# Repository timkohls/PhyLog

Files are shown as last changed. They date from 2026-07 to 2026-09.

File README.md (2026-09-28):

<div align="center">
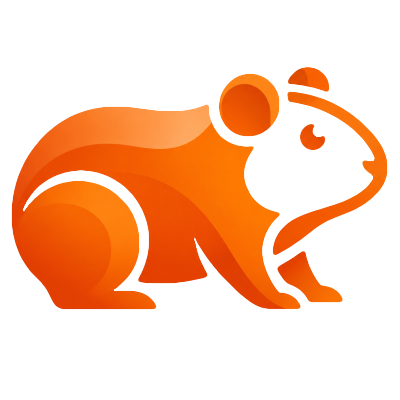
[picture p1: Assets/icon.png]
PhyLog Logo
  

# PhyLog

Digitale Messwerterfassung für den Physikunterricht, ein ESP32, die wichtigsten Sensoren, unter 50 € pro Messplatz.

</div>

---

## Worum geht's

> „Ziel ist nicht das bessere Messgerät zu entwickeln, sondern mehr selbstständiges Experimentieren zu ermöglichen."

Ein Klassensatz Vernier - oder Leybold-Equipment kostet schnell so viel wie ein Kleinwagen – entsprechend selten stehen genug Geräte für echtes Experimentieren zur Verfügungund aus vielen Versuchen werden Frontalvorführungen. PhyLog will das ändern, ein ESP32 und austauschbare Sensormodule ergeben einen Messplatz für einen Bruchteil der üblichen Kosten. Steckbar, offen dokumentiert und mit einer Desktop-Software, die live mitschreibt.

**Woraus das Ganze besteht:**

<div align="center">
  PhyLog Architektur: Software, ESP32, Sensormodule
</div>

---

Die Hardware besteht aus dem ESP32-Hub und den verschiedenen steckbaren Sensormodulen. Alle benötigten 3D-Druckdateien, Pinouts und weiteren Hardware-Dateien befinden sich im Hardware-Ordner.

Wenn du einen eigenen PhyLog-Messplatz aufbauen möchtest, findest du dort auch eine ausführliche Hardware Quickstart-Anleitung. Diese beschreibt den Aufbau und die Verkabelung der Sensoren und des ESP32-Hubs sowie die Installation der benötigten Treiber, das Aufspielen der Firmware und die erste Verbindung mit PhyLog.

---

## Quickstart

1. **PhyLog anschließen.** Per USB-Kabel oder – wenn das Board vorher schon einmal gekoppelt wurde – per Bluetooth. Oben rechts im Hauptfenster Com-Port auswählen und "Verbinden" klicken oder die Lupe dann sucht PhyLog den richtigen Port automatisch über einen kurzen Handshake.
2. **Sensoren zuweisen.** Über *Sensor → Sensor konfigurieren…* für Kanal A und/oder B den passenden Sensortyp wählen und bei Bedarf kalibrieren (siehe unten). Live-Werte zeigt der Dialog dabei direkt an, man sieht also sofort, ob der Sensor etwas liefert.
3. Mit **Start** loslegen. Ohne Schwellenwert-Trigger beginnt die Aufzeichnung sofort; mit Trigger wartet PhyLog, bis die konfigurierte Flanke auftritt, und nimmt dank Vorlaufpuffer auch die Millisekunden *vor* dem eigentlichen Auslöser mit auf.
4. **Auswerten.** Im Diagramm zoomen (Rubberband oder Freihand), einen Fit durchlegen, Chi² ablesen – und am Ende als CSV oder PNG rausschreiben.

Wer nur schnell einen einzelnen Messwert braucht (z. B. für eine Wertetabelle mit mehreren Positionen statt einer Zeitreihe), nutzt statt "Start" den **Momentaufnahme**-Knopf: der trägt den aktuellen Live-Wert als neue Zeile mit fortlaufendem Index statt Zeitstempel ein.

---

## Was die Software kann

**Live-Erfassung & Trigger**
Zwei unabhängige Kanäle (A/B), durchgehendes Streaming vom Gerät, sodass Live-Anzeigen und Kalibrierung auch ohne laufende Aufzeichnung aktuelle Werte zeigen. Start entweder manuell per Knopfdruck oder über einen Schwellenwert-Trigger (steigende/fallende Flanke, einstellbare Vorlaufzeit, optionales Zeitlimit).

**Diagramm**
Zoomen per Rubberband oder Freihand-Auswahl, Zoom-Buttons, gemeinsame oder getrennte Y-Achse für Kanal A/B, gerade/glatte (Spline) Linienverbindung. Regressionen für linear, Polynom (Grad wählbar), Sinus und Exponentialfunktion, dazu reduziertes Chi² zur Bewertung der Fit-Güte – inklusive automatischer Sigma-Schätzung aus den Residuen, falls keine Messunsicherheit von Hand eingetragen wurde.

**Sensoren (steckbar)**
INA219 für Strom, VEML7700 für Beleuchtungsstärke, HX711 für Kraft/Gewicht, INMP441-Mikrofon (als Schalldruckpegel oder live als Frequenzspektrum), ein KY-003-Hall-Sensor für Drehzahl-/Periodendauermessungen sowie ein generischer 0–16V-Spannungsteiler und ein DS18B20-Digitalthermometer. Jeder Sensor mit Kalibrierbedarf bringt seinen eigenen Dialog mit.

**Import/Export**
CSV-Import gezielt pro Kanal (die Software fragt beim Öffnen, ob die Datei nach A oder B soll – so lassen sich zwei frühere Messungen nacheinander laden, ohne dass sich die Kanäle gegenseitig überschreiben), CSV-Export getrennt je Kanal, Diagramm-Export als PNG.

**Verbindung**
USB und Bluetooth SPP, automatische Geräteerkennung per Handshake statt Rate-Raten über die COM-Port-Liste, ein eingebautes Terminal für rohe Kommandos an die Firmware.

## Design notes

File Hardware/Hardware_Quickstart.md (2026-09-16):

# PhyLog Hardware – Quickstart

Dieser Quickstart beschreibt den Aufbau der PhyLog-Hardware sowie das erste Bespielen und Verbinden des ESP32.

PhyLog besteht aus einem ESP32-Hub und verschiedenen steckbaren Sensormodulen. Die Sensormodule können je nach benötigter Messgröße ausgetauscht und erweitert werden. Die verfügbaren Sensoren und die zugehörigen Hardware-Dateien befinden sich im Ordner [`Hardware/prints`](https://github.com/timkohls/PhyLog/tree/main/Hardware/prints).

## 1. 3D-Druck

Alle benötigten Gehäuseteile müssen zunächst ausgedruckt werden.

Für den ESP32 wird einmal der

- `ESP_Bottom`

- `ESP_Top`

benötigt.

Für die Sensoren gibt es ein gemeinsames `Sensor_Top`, das für alle Sensoren verwendet werden kann. Für jeden Sensortyp wird zusätzlich das jeweils passende `*_Sensor_Bottom` benötigt.

Die Anzahl der zu druckenden Sensor-Bottoms richtet sich daher danach, wie viele Sensoren des jeweiligen Typs gebaut werden sollen.

Aktuell liegen unter anderem Bottoms für Strom, Spannung, Kraft, Licht, Magnetfeld, Schall und Temperatur sowie ein gemeinsames Sensor-Top und ESP-Gehäuse im Repository.

## 2. Sensoren aufbauen

Die jeweilige Sensorplatine wird in das passende Bottom eingesetzt und mit **M3 × 4 mm Schrauben** befestigt.

Die Verdrahtung zwischen Sensor und ESP32 ist dem [Pinout](https://github.com/timkohls/PhyLog/blob/main/Hardware/pinout.md) zu entnehmen. Dort ist für die verschiedenen Sensortypen angegeben, welche RJ45-Pins mit welchen ESP32-Pins verbunden werden müssen.

Dabei gilt grundsätzlich:

- **Pin 1:** GND

- **Pin 8:** VCC

- Die übrigen verwendeten Pins hängen vom Sensortyp und vom verwendeten Kommunikationsprotokoll ab.

Nach dem Einsetzen und Verkabeln wird das gemeinsame Sensor-Top aufgesetzt und ebenfalls mit **M3 × 4 mm Schrauben** befestigt.

Damit ist das Sensormodul fertig.

Der ESP32-Hub wird auf die gleiche Weise aufgebaut: ESP32 in das `ESP_Bottom` einsetzen, befestigen und anschließend das `ESP_Top` mit M3 × 4 mm Schrauben verschließen.

## 4. Firmware auf den ESP32 spielen

Bevor ein ESP32 zum ersten Mal bespielt werden kann, muss auf dem verwendeten Rechner der passende **CH340/CH341-Treiber** installiert werden.

Der benötigte Treiber befindet sich bereits im Repository unter:

```
Firmware/CH341SER/
```

Der dort enthaltene Treiber wurde von der **Nanjing Qinheng Microelectronics (WCH)**-Website heruntergeladen und unverändert in das Repository übernommen. Er ist **kein Bestandteil der PhyLog-Software**, sondern eine benötigte Drittanbieter-Komponente, die für die USB-Kommunikation mit dem ESP32 bereitgestellt wird.

Die Originalquelle des Treibers ist:

**WCH – CH341SER USB-to-Serial Driver**  
https://www.wch-ic.com/downloads/CH341SER_ZIP.html

Die Firmware befindet sich unter:

```text
Firmware/PhyLog_firmware/PhyLog_firmware.ino
```

Die `.ino`-Datei kann direkt mit der **Arduino IDE** geöffnet werden.

Arduino erkennt die benötigten Bibliotheken normalerweise automatisch. Falls die ESP32-Unterstützung noch nicht installiert ist, muss das **ESP32 Dev Module** bzw. die ESP32-Board-Unterstützung über den Board Manager installiert werden.

Die Installation kann etwas dauern, da Arduino dabei zusätzliche Komponenten herunterlädt. Die offizielle ESP32-Unterstützung wird über das Arduino-ESP32-Paket bereitgestellt.

Anschließend:

1. ESP32 per USB mit dem Rechner verbinden.

2. In Arduino das entsprechende **ESP32 Dev Module** auswählen.

3. Den vom ESP32 verwendeten **COM-Port** auswählen.

4. Die Firmware mit **Upload** auf den ESP32 übertragen.

5. Warten, bis Arduino **`Upload Done`** meldet.

Falls der ESP32 nicht als COM-Port auftaucht, zunächst überprüfen, ob der CH340/CH341-Treiber korrekt installiert wurde.

## 5. Erste Verbindung mit PhyLog

Nach erfolgreichem Flashen kann der ESP32 zum ersten Mal mit der PhyLog-Software verbunden werden.

Am einfachsten ist die erste Verbindung zunächst über **USB**.

ESP32 anschließen und in PhyLog oben rechts die Verbindung herstellen. Der bevorzugte Weg ist die **automatische Portsuche**. PhyLog sucht dabei nach dem passenden Gerät und überprüft die Verbindung über einen Handshake.

Alternativ kann der COM-Port auch manuell über das Dropdown-Menü ausgewählt werden.

### Verbindung testen

Um zu überprüfen, ob die Firmware korrekt funktioniert, kann das integrierte **Terminal** geöffnet werden.

Den ESP32 einmal anpingen.

Wenn alles korrekt funktioniert, sollte eine **Hello-Antwort mit der entsprechenden Firmware-/Payload-Version** zurückkommen.

Ist dies der Fall, funktionieren:

- ESP32

- USB-Verbindung

- Treiber

- Firmware

- Kommunikation mit PhyLog

korrekt.

## 6. Fehlerbehebung bei USB

Wenn kein COM-Port angezeigt wird oder keine Verbindung hergestellt werden kann, sollten die folgenden Punkte überprüft werden:

1. Ist der CH340/CH341-Treiber installiert?

2. Wird der ESP32 im Geräte-Manager als COM-Port erkannt?

3. Ist in Arduino das richtige ESP32-Board ausgewählt?

4. Wurde die Firmware erfolgreich mit **`Upload Done`** übertragen?

5. Ist der richtige COM-Port ausgewählt?

6. Funktioniert die Kommunikation über das PhyLog-Terminal?

Wenn der ESP32 bereits erfolgreich geflasht wurde, aber keine Verbindung zustande kommt, sollte zunächst der USB-Anschluss und anschließend die automatische bzw. manuelle COM-Port-Auswahl überprüft werden.

## 7. Verbindung über Bluetooth

PhyLog unterstützt neben USB auch **Bluetooth SPP**.

Wenn Bluetooth verwendet werden soll, muss der ESP32 auf jedem Rechner, mit dem er verwendet werden soll, zunächst einmal ganz normal über die Bluetooth-Einstellungen des Betriebssystems gekoppelt werden.

Dazu:

1. ESP32 mit Strom versorgen.

2. Bluetooth-Einstellungen des Rechners öffnen.

3. Den ESP32 auswählen und koppeln.

4. PhyLog starten.

5. Oben rechts die automatische Portsuche verwenden oder den entsprechenden Port manuell auswählen.

> **Hinweis:** Die Bluetooth-Suche dauert etwas länger als die USB-Suche. Währenddessen zeigt PhyLog oben im Statusbereich an, was gerade passiert.

Nach erfolgreicher Verbindung kann der ESP32 genauso wie über USB verwendet werden.

## 8. Kurzfassung

```text
3D-Druck
   ↓
ESP-Bottom + ESP-Top
Sensor-Bottom + gemeinsames Sensor-Top
   ↓
Sensorplatinen mit M3 × 4 mm befestigen
   ↓
Nach pinout.md verkabeln
   ↓
Gehäuse schließen
   ↓
CH340/CH341-Treiber installieren
   ↓
PhyLog_firmware.ino in Arduino öffnen
   ↓
ESP32 Dev Module auswählen
   ↓
COM-Port auswählen
   ↓
Firmware hochladen
   ↓
"Upload Done"
   ↓
ESP32 mit PhyLog verbinden
   ↓
Terminal öffnen und ESP32 anpingen
   ↓
Hello + Payload-Version erhalten
   ↓
Fertig
```

Weitere Informationen zu Pinbelegung, Hardware und verfügbaren Komponenten befinden sich direkt im `Hardware`-Ordner des Projekts.

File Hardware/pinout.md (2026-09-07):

# Pinout

| **RJ45-Pin** | **Sensor A (ESP-Pin)** | **Sensor B (ESP-Pin)** | **I2C-Sensor** | **I2S-Sensor** | **2WS-Sensor** | **Analog-Sensor** |
| --- | --- | --- | --- | --- | --- | --- |
| **1** | Ground | Ground | Ground | Ground | Ground | Ground |
| **2** | D32 | D27 | SDA | WS | DOUT | Analog |
| **3** | D33 | D26 | SCL | SCK | SCK | *leer* |
| **4** | D35 | D25 | *leer* | SD | *leer* | *leer* |
| **5** | *leer* | *leer* | *leer* | *leer* | *leer* | *leer* |
| **6** | *leer* | *leer* | *leer* | *leer* | *leer* | *leer* |
| **7** | *leer* | *leer* | *leer* | *leer* | *leer* | *leer* |
| **8** | VCC | VCC | VCC | VCC | VCC | VCC |
| **9** | *leer* | *leer* | *leer* | *leer* | *leer* | *leer* |

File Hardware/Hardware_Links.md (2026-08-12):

# Preisliste Hardware

| Menge | Hardware | Links | Preis (nach Menge) |
| ----- | --- | --- | --- |
| 1/2 x | ESP 32 | https://www.amazon.de/dp/B0DHRV7784 | 5,49 € |
| 1/2 x | Strom | https://www.amazon.de/dp/B0FWJV9V54 | 2,99 € |
| 1/5 x | Spannung | https://www.amazon.de/-/en/dp/B07DJ5TGL8 | 0,99 € |
| 1/2 x | Wägezelle | https://www.amazon.de/dp/B0G6YGMVN9 | 5,09 € |
| 1/2 x | Lichtsensor | https://www.amazon.de/dp/B0C3VC5H6M | 4,49 € |
| 1/3 x | Schallsensor | https://www.amazon.de/dp/B0GXZC7T7H | 2,49 € |
| 1/5 x | Temperatursensor (+Spannungsteiler s. o.) | https://www.amazon.de/dp/B0GLXCGXCW | 2,98 € |
| 1/5 x | Hallsonde | https://www.amazon.de/dp/B07DJ5HXHM | 0,99 € |
| 1 x | RJ45 (Pack of 7) | https://www.amazon.de/dp/B0F4MWBK5H | 8,99 € |
| 2 x | RJ45 Cable | https://www.amazon.de/dp/B00N2VILDM | 3,98 € |
| 1 x | Jumper Cable (40) | https://www.amazon.de/dp/B07KYHBVR7 | 2,49 € |
| 1/5 x | PLA (200g) | https://www.amazon.de/dp/B0BTHSVQ89/ | 2,99 € |
| 1/4 x | Schrauben | https://www.amazon.de/dp/B0GYTDFYBG | 2,09 € |
| | | | **46,05 €** |

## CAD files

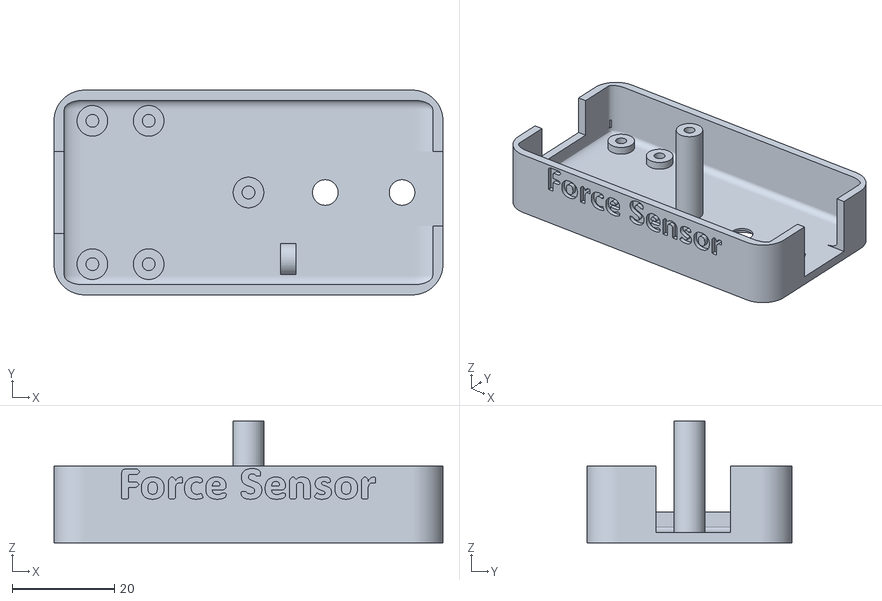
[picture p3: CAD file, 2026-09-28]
Hardware/prints/Force_Sensor_Bottom_V1.3.stl
76.0 x 40.0 x 23.8

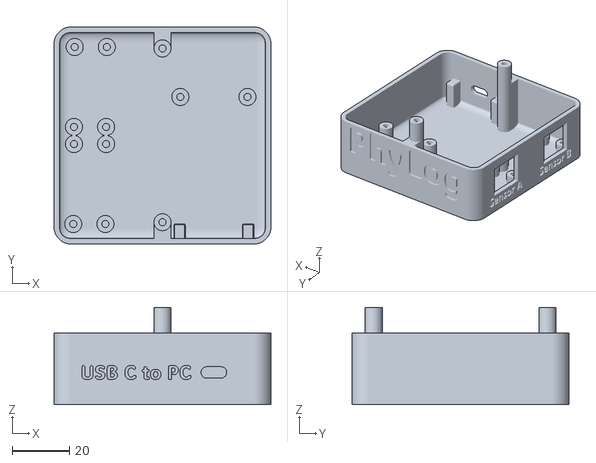
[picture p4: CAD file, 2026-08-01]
Hardware/prints/ESP_Bottom_V1.6.stl
76.0 x 76.0 x 34.0

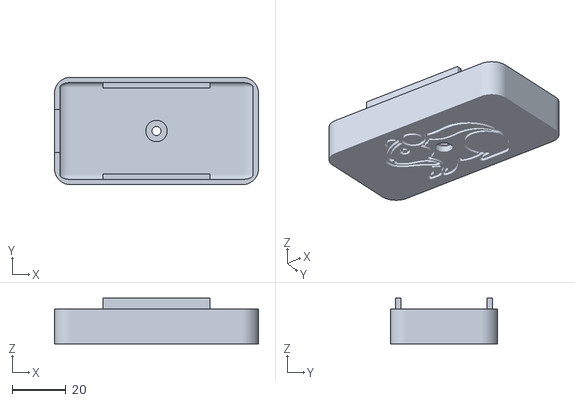
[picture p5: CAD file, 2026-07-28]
Hardware/prints/Sensor_Top_V1.5.stl
76.0 x 40.0 x 17.0

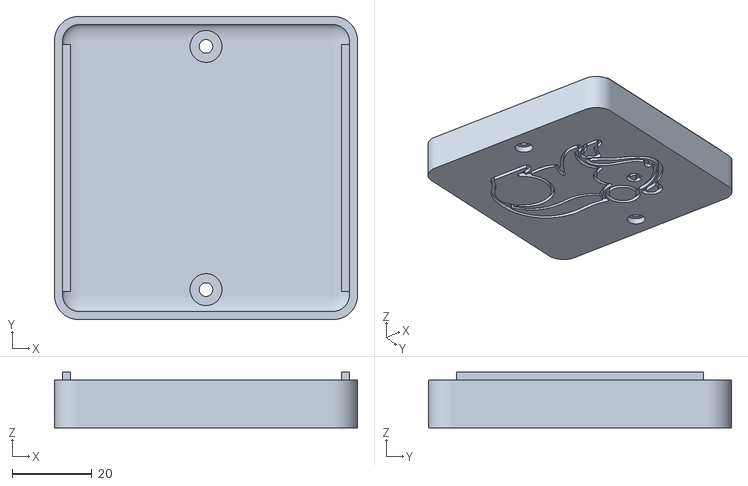
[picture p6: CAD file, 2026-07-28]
Hardware/prints/ESP_Top_V1.3.stl
76.0 x 76.0 x 14.0

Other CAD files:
Hardware/prints/Voltage_Sensor_Bottom_V1.1.stl
Hardware/prints/Temperature_Sensor_Bottom_V1.0.stl
Hardware/prints/Magnet_Sensor_Bottom_V1.1.stl
Hardware/prints/Light_Sensor_Bottom_V1.5.stl
Hardware/prints/Sound_Sensor_Bottom_V1.4.stl
Hardware/prints/Current_Sensor_Bottom_V1.4.stl

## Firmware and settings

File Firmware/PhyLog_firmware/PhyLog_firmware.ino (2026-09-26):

/*
 * PhyLog Firmware v9.2
 *
 * Steuert zwei unabhängige Messkanäle (A/B) über USB und Bluetooth. Ein Kanal bekommt seinen
 * Sensortyp per SET,<Kanal>,<Typ>[,<Konfiguration>] vom Host zugewiesen und startet immer bei
 * TYPE_NONE. Die Firmware kennt dabei keine konkreten Sensormodelle, nur generische Bus-Muster:
 *
 *   ANALOG    Pin2=Eingang                           keine Konfiguration
 *   DIGITAL   Pin2=Eingang                           keine Konfiguration
 *   I2C       Pin2=SDA, Pin3=SCL                     Adresse + Init-/Lese-Register, siehe parseI2CSetPayload
 *   I2S       Pin2=WS, Pin3=BCLK, Pin4=SD            Modus, Abtastrate, Slot, Bit-Shift, Null-Check, siehe parseI2SSetPayload
 *   ONEWIRE   Pin2=Datenleitung (ext. Pull-up 4,7kΩ) opt. Init-Writes + Konversions-/Lesekommando + Byte-Layout, siehe parseOneWireSetPayload
 *   HX711     Pin2=DOUT, Pin3=SCK                    keine Konfiguration (eigenes Protokoll)
 *
 * Ein neuer Sensor mit einer dieser Schnittstellen braucht deshalb kein Firmware-Update, nur eine
 * neue Java-Klasse (siehe I2CSensor.java/OneWireSensor.java/I2SSensor.java). Vorausgesetzt wird
 * dabei das jeweilige generische Muster - ein grundlegend anderes Protokoll bräuchte weiterhin ein Firmware-Update.
 *
 * Kanal A und B hängen an physisch getrennten Bussen (I2C: Wire/Wire1, I2S: Port 0/1), damit
 * beide gleichzeitig denselben Typ nutzen können.
 *
 * Host-Protokoll (zeilenbasiert, '\n'-terminiert, identisch über USB und Bluetooth):
 *   Host -> ESP32:  PING | START | STOP | RATE,<Hz> | SET,<Kanal>,<Typ>[,<Konfiguration>]
 *   ESP32 -> Host:  #HELLO,...              Antwort auf PING sowie einmalig beim Start
 *                   #OK,<Kommando>[,...]    Bestätigung
 *                   #ERR,<Tag>,<Kanal>      Sensor-/Konfigurationsfehler (gedrosselt, siehe reportSensorError)
 *                   D,<ms>,<Kanal>,<Slot>,<Rohwert>          ein Messwert (siehe sendDataPacket)
 *                   #SPEC,<Kanal>,<Bins>,<Rate>,<dB*10>,...   ein Frequenzspektrum (siehe sendSpectrumPacket)
 *
 * Aufbau dieser Datei:
 *   1. Konstanten    2. Typen/Structs    3. Laufzeitzustand    4. Host-Kommunikation
 *   5. Low-Level-GPIO    6. Sensortreiber (I2C, HX711, 1-Wire, I2S inkl. FFT)
 *   7. Kanal-Hardware (Freigabe/Konfiguration)    8. Parser für SET-Payloads
 *   9. Kommando-Verarbeitung    10. Abtast-Dispatcher    11. setup()/loop()
 *
 * Hardware-Notizen:
 * - Kanal-A-Pins: GPIO32/33/35 (ADC1-fähig, keine Strapping-Pins). Kanal B: GPIO27/26/25.
 *   Nicht ändern, ohne ADC-Tauglichkeit/Strapping-Pin-Eigenschaften der Ziel-GPIOs zu prüfen.
 * - HX711 und 1-Wire nutzen direkten GPIO-Registerzugriff statt digitalWrite()/digitalRead(),
 *   da deren IO-MUX-Overhead das µs-genaue Timing beider Protokolle sprengen würde.
 */

#include <Wire.h>
#include <driver/i2s_std.h>
#include <math.h>
#include "soc/gpio_struct.h"
#include "BluetoothSerial.h"

#if !defined(CONFIG_BT_ENABLED) || !defined(CONFIG_BLUEDROID_ENABLED)
#error Bluetooth ist im Board-/Menuconfig-Profil deaktiviert - Partition Scheme mit \
       Bluetooth-Unterstützung wählen (siehe Dateikopf).
#endif


// =====================================================================================
// 1. KONSTANTEN
// =====================================================================================

// --- Allgemein / Host-Verbindung ---

/** Begrüßungszeile, Antwort auf PING und einmalige Meldung beim Start. */
const char *HELLO_MESSAGE = "#HELLO,PhyLog-ESP32,fw=9.2\n";

/** Serielle Baudrate zum PC - muss mit GUI.java (DeviceConnection.connect) und Terminal.java
 *  übereinstimmen, sonst verbindet sich nichts mehr. */
const long BAUD_RATE = 460800;

/** Name in der Bluetooth-Geräteliste des PCs. */
const char *BT_DEVICE_NAME = "PhyLog Bluetooth";

/** Mindestabstand zwischen zwei an den Host gemeldeten Fehlern desselben Kanals, damit ein
 *  dauerhaft fehlschlagender Sensor den Host nicht mit #ERR-Zeilen flutet. */
const unsigned long ERROR_REPORT_MIN_INTERVAL_MS = 120;

// --- Pinbelegung ---

/** Die drei Signal-Pins eines Kanal-Ports, Rolle je nach Sensortyp (siehe
 *  configureChannelHardware): I2C=SDA/SCL, HX711=DOUT/SCK, I2S=WS/BCLK/SD, Analog/Digital/
 *  1-Wire nutzen nur [0]. GPIO 0/2/5/12/15 sind ESP32-Strapping-Pins und bewusst nicht belegt. */
const int PINS_CHANNEL_A[3] = {32, 33, 35};
const int PINS_CHANNEL_B[3] = {27, 26, 25};

// --- I2C ---

/** Anzahl aufeinanderfolgender I2C-Fehler je Kanal, ab der der Bus automatisch neu
 *  initialisiert wird (siehe noteI2CResult). */
const int I2C_FAIL_STREAK_RESET_THRESHOLD = 20;

// --- HX711 ---

/** Maximale Zeit in ms, die DOUT durchgehend HIGH bleiben darf, bevor ein HX711-Fehler gemeldet
 *  wird (siehe sampleHX711). */
const unsigned long HX711_TIMEOUT_MS = 1000;

// --- I2S-Mikrofon ---

/** Wie viele I2S-Rohsamples je Zyklus für den Spitzenwert gelesen werden, richtet sich dynamisch
 *  nach der konfigurierten Abtastrate (siehe i2sReadSampleCount), begrenzt auf diesen Bereich. */
const int MIC_MIN_READ_SAMPLES = 16;
const int MIC_MAX_READ_SAMPLES = 512;

/** Anzahl aufeinanderfolgender komplett nullwertiger I2S-Fenster, ab der erst von einer echten
 *  Diskonnektion statt einer legitimen kurzen Stille ausgegangen wird (siehe sampleI2SRaw/
 *  captureAndSendSpectrum). */
const int I2S_ZERO_STREAK_THRESHOLD = 5;

// --- Frequenzspektrum (I2S im Modus SPEC) ---

/** FFT-Größe für den Live-Frequenzspektrum-Modus - Zweierpotenz (Voraussetzung der iterativen
 *  Radix-2-FFT in computeFFT). Ein reelles Signal liefert nur n/2 unabhängige Frequenz-Bins. */
const int SPECTRUM_FFT_SIZE = 1024;
const int SPECTRUM_OUTPUT_BINS = SPECTRUM_FFT_SIZE / 2;

/** Puffergröße für ein komplettes Spektrum-Paket (Header + je Bin bis zu 6 Byte, siehe
 *  sendSpectrumPacket), großzügig genug ohne Neuberechnung pro Bild. */
const size_t SPECTRUM_PACKET_BUF_SIZE = 32 + (size_t) SPECTRUM_OUTPUT_BINS * 7;

/** Mindestabstand zwischen zwei gesendeten Spektren (~16 Bilder/Sekunde bei BAUD_RATE=460800). */
const unsigned long SPECTRUM_INTERVAL_MS = 60;


// =====================================================================================
// 2. TYPEN UND STRUCTS
// =====================================================================================
// Alle Typen stehen bewusst vor jeder Funktion/jedem Prototyp: Die Arduino-IDE fügt
// automatisch generierte Prototypen vor den ersten Funktionen ein, und die müssen die hier
// definierten Typen bereits kennen.

/** Sensortyp eines Kanals. Die Zahlenwerte werden nicht übertragen (das Protokoll nutzt
 *  Klartext-Typnamen), die Lücken bei 3 und 6 haben daher keine Funktion. */
enum SensorType {
  TYPE_NONE = 0,
  TYPE_ANALOG = 1,
  TYPE_I2C = 2,
  TYPE_HX711 = 4,
  TYPE_I2S = 5,
  TYPE_DIGITAL = 7,
  TYPE_ONEWIRE = 8
};

// --- I2C ---

/** Ein Registerschreibvorgang der I2C-Init-Sequenz. */
struct I2CWriteSpec {
  uint8_t reg = 0;
  uint8_t data[4] = {0, 0, 0, 0};
  uint8_t dataLen = 0;
};

/** Ein Register-Lesevorgang je Abtastzyklus eines I2C-Sensors. */
struct I2CReadSpec {
  uint8_t reg = 0;
  uint8_t len = 0;      // 1-4 Byte
  bool bigEndian = true;
  uint8_t slot = 0;
};

const uint8_t MAX_I2C_WRITES = 4;
const uint8_t MAX_I2C_READS = 4;

/** Vom Host per SET-Kommando übertragene I2C-Sensorkonfiguration eines Kanals. */
struct I2CSensorConfig {
  uint8_t address = 0;
  I2CWriteSpec initWrites[MAX_I2C_WRITES];
  uint8_t initWriteCount = 0;
  I2CReadSpec reads[MAX_I2C_READS];
  uint8_t readCount = 0;
};

// --- I2S ---

/** Vom Host per SET-Kommando übertragene I2S-Sensorkonfiguration eines Kanals. */
struct I2SSensorConfig {
  bool spectrumMode = false;
  uint32_t sampleRateHz = 16000;
  bool selectRightSlot = false;  // Slot-Auswahl je nach SEL-Pin-Verdrahtung des Moduls
  uint8_t shiftBits = 8;         // Shift zur Extraktion der gültigen Bits, siehe parseI2SSetPayload
  bool zeroIsError = true;       // durchgängiger Nullwert = Verkabelungsfehler
};

// --- 1-Wire ---

/** Ein einzelner Kommando-Schreibvorgang der 1-Wire-Init-Sequenz (z.B. "Write Scratchpad" beim
 *  DS18B20 zur Auflösungseinstellung). Jeder Eintrag bekommt vor dem Senden von {@code command}
 *  und {@code data} eine eigene Reset+Skip-ROM-Sequenz vorangestellt, siehe configureOneWireSensor. */
struct OneWireWriteSpec {
  uint8_t command = 0;
  uint8_t data[4] = {0, 0, 0, 0};
  uint8_t dataLen = 0;
};

const uint8_t MAX_ONEWIRE_WRITES = 2;

/** Generische 1-Wire-Sensorbeschreibung. "Skip ROM" (0xCC) nimmt die Firmware selbst an -
 *  unterstützt wird nur ein Sensor pro Bus. */
struct OneWireSensorConfig {
  OneWireWriteSpec initWrites[MAX_ONEWIRE_WRITES];
  uint8_t initWriteCount = 0;
  uint8_t convertCmd = 0;
  unsigned long conversionDelayMs = 0;
  uint8_t readCmd = 0;
  uint8_t readLen = 0;
  uint8_t valueOffset = 0;
  uint8_t valueLen = 0;
  bool littleEndian = true;
  bool checkCrc = true;
  uint8_t slot = 0;
};

// --- Prototypen für Funktionen mit Struct-Parametern/-Rückgabewerten ---
// Arduino generiert für alle unten definierten Funktionen automatisch Prototypen, noch bevor
// die obigen Structs bekannt sind - das schlägt für Funktionen mit Struct-Typen in der
// Signatur fehl. Fix: eigene Prototypen hier, direkt nach den Structs (die Arduino-IDE
// erzeugt für bereits deklarierte Funktionen keinen zweiten).
I2CSensorConfig &i2cConfigForChannel(char channelName);
I2SSensorConfig &i2sConfigForChannel(char channelName);
OneWireSensorConfig &oneWireConfigForChannel(char channelName);
bool readOneWireResult(int pin, const OneWireSensorConfig &cfg, long &outValue);
bool parseI2CWriteEntry(const String &entry, I2CWriteSpec &out);
bool parseI2CReadEntry(const String &entry, I2CReadSpec &out);
bool parseI2CWriteList(const String &list, I2CWriteSpec specs[], uint8_t &countOut, uint8_t maxCount);
bool parseI2CReadList(const String &list, I2CReadSpec specs[], uint8_t &countOut, uint8_t maxCount);
bool parseI2SSetPayload(char channelName, const String &params);
bool parseOneWireWriteEntry(const String &entry, OneWireWriteSpec &out);
bool parseOneWireWriteList(const String &list, OneWireWriteSpec specs[], uint8_t &countOut, uint8_t maxCount);


// =====================================================================================
// 3. LAUFZEITZUSTAND
// =====================================================================================

BluetoothSerial SerialBT;

// --- Streaming und Abtasttakt ---

bool isStreaming = false;
unsigned long sampleIntervalMs = 50; // Standard: 20 Hz
unsigned long lastSampleTimeMs = 0;

// --- Sensortyp und Konfiguration je Kanal ---

SensorType configChannelA = TYPE_NONE;
SensorType configChannelB = TYPE_NONE;

I2CSensorConfig i2cConfigChannelA;
I2CSensorConfig i2cConfigChannelB;

I2SSensorConfig i2sConfigChannelA;
I2SSensorConfig i2sConfigChannelB;

OneWireSensorConfig oneWireConfigChannelA;
OneWireSensorConfig oneWireConfigChannelB;

// --- Fehlerdrosselung (siehe reportSensorError) ---

/** Letzter Zeitpunkt einer gemeldeten Fehlermeldung je Kanal. */
unsigned long lastErrorReportMsA = 0;
unsigned long lastErrorReportMsB = 0;

// --- I2C (siehe noteI2CResult) ---

/** Aufeinanderfolgende I2C-Fehler je Kanal. */
int i2cFailStreakA = 0;
int i2cFailStreakB = 0;

// --- HX711 (siehe sampleHX711) ---

/** Ob DOUT aktuell durchgehend HIGH ist (noch kein neuer Wert bereit) und seit wann - Basis für
 *  den Timeout in sampleHX711. Bei Kanalwechsel über releaseChannelHardware zurückgesetzt. */
bool hx711WaitingA = false;
bool hx711WaitingB = false;
unsigned long hx711WaitStartMsA = 0;
unsigned long hx711WaitStartMsB = 0;

// --- 1-Wire (siehe sampleOneWire) ---

/** Ob für den Kanal aktuell eine Konversion läuft, deren Ergebnis noch nicht abgeholt wurde,
 *  und wann sie gestartet wurde. Bei Kanalwechsel über releaseChannelHardware zurückgesetzt. */
bool oneWireConversionPendingA = false;
bool oneWireConversionPendingB = false;
unsigned long oneWireConversionStartMsA = 0;
unsigned long oneWireConversionStartMsB = 0;

// --- I2S (siehe configureI2S, sampleI2SRaw, captureAndSendSpectrum) ---

i2s_chan_handle_t micHandleA = NULL;
i2s_chan_handle_t micHandleB = NULL;

/** Aufeinanderfolgende komplett nullwertige I2S-Fenster je Kanal, siehe I2S_ZERO_STREAK_THRESHOLD. */
int i2sZeroStreakA = 0;
int i2sZeroStreakB = 0;

/** Zeitpunkt des zuletzt gesendeten Spektrums je Kanal. */
unsigned long lastSpectrumTimeMsA = 0;
unsigned long lastSpectrumTimeMsB = 0;

/** Vorberechnetes Hann-Fenster für captureAndSendSpectrum - identisch für jeden Frame, spart
 *  Neuberechnung je Frame. */
float hannWindow[SPECTRUM_FFT_SIZE];
bool hannWindowReady = false;


// =====================================================================================
// 4. HOST-KOMMUNIKATION UND KANAL-ZUORDNUNG
// =====================================================================================

/** hostWrite()/hostPrint() schreiben immer auf USB und zusätzlich auf Bluetooth, sofern dort
 *  ein Client verbunden ist. */
void hostWrite(const char *data, size_t len) {
  Serial.write((const uint8_t *) data, len);
  if (SerialBT.hasClient()) {
    SerialBT.write((const uint8_t *) data, len);
  }
}

void hostPrint(const char *s) {
  hostWrite(s, strlen(s));
}

/** Verschickt einen Messwert als Zeile {@code D,<millis>,<Kanal>,<Slot>,<Rohwert>}. Der Slot
 *  unterscheidet mehrere Werte eines Sensors (z.B. Strom/Spannung beim INA219). */
void sendDataPacket(char channel, int slot, long rawValue) {
  char buf[48];
  int len = snprintf(buf, sizeof(buf), "D,%lu,%c,%d,%ld\n", millis(), channel, slot, rawValue);
  hostWrite(buf, len);
}

/** Meldet einen fehlgeschlagenen Sensorzugriff als {@code #ERR,<Tag>,<Kanal>} (gedrosselt auf
 *  ERROR_REPORT_MIN_INTERVAL_MS je Kanal). */
void reportSensorError(char channelName, const char *errorTag) {
  unsigned long &lastReport = (channelName == 'A') ? lastErrorReportMsA : lastErrorReportMsB;
  unsigned long now = millis();
  if (now - lastReport >= ERROR_REPORT_MIN_INTERVAL_MS) {
    lastReport = now;
    char buf[48];
    int len = snprintf(buf, sizeof(buf), "#ERR,%s,%c\n", errorTag, channelName);
    hostWrite(buf, len);
  }
}

// --- Zuordnung Kanalname -> physische Ressource ---

I2CSensorConfig &i2cConfigForChannel(char channelName) {
  return (channelName == 'A') ? i2cConfigChannelA : i2cConfigChannelB;
}

I2SSensorConfig &i2sConfigForChannel(char channelName) {
  return (channelName == 'A') ? i2sConfigChannelA : i2sConfigChannelB;
}

OneWireSensorConfig &oneWireConfigForChannel(char channelName) {
  return (channelName == 'A') ? oneWireConfigChannelA : oneWireConfigChannelB;
}

/** @return den I2C-Bus, der physisch zu diesem Kanal gehört. */
TwoWire &busForChannel(char channelName) {
  return (channelName == 'A') ? Wire : Wire1;
}

/** @return den I2S-Port, der physisch zu diesem Kanal gehört. */
i2s_port_t i2sPortForChannel(char channelName) {
  return (channelName == 'A') ? I2S_NUM_0 : I2S_NUM_1;
}

/** @return das I2S-Channel-Handle, das physisch zu diesem Kanal gehört. */
i2s_chan_handle_t &micHandleForChannel(char channelName) {
  return (channelName == 'A') ? micHandleA : micHandleB;
}


// =====================================================================================
// 5. LOW-LEVEL-GPIO (direkter Registerzugriff)
// =====================================================================================
// GPIO32-39 hängen beim ESP32 an einem zweiten Register-Satz (out1/enable1/in1), daher die
// Fallunterscheidung "pin < 32" in allen Helfern.

/** Setzt {@code pin} direkt über das Register auf HIGH/LOW - kostet nur wenige Taktzyklen statt
 *  mehrerer hundert ns (IO-MUX-Overhead von digitalWrite()), was bei den µs-genauen HX711-
 *  Zeitfenstern zählt. Setzt voraus, dass der Pin bereits per pinMode(pin, OUTPUT) konfiguriert
 *  ist. */
static inline void gpioWriteFast(int pin, bool high) {
  if (pin < 32) {
    if (high) GPIO.out_w1ts = (1U << pin);
    else      GPIO.out_w1tc = (1U << pin);
  } else {
    if (high) GPIO.out1_w1ts.val = (1U << (pin - 32));
    else      GPIO.out1_w1tc.val = (1U << (pin - 32));
  }
}

/** Liest den aktuellen Pegel von {@code pin} (0 oder 1). */
static inline int gpioReadFast(int pin) {
  if (pin < 32) {
    return (GPIO.in >> pin) & 0x1;
  } else {
    return (GPIO.in1.data >> (pin - 32)) & 0x1;
  }
}

/** Zieht {@code pin} aktiv auf LOW (Open-Drain-Charakter von 1-Wire: nur Treiben nach LOW,
 *  niemals aktiv nach HIGH - siehe owRelease). */
static inline void owLow(int pin) {
  if (pin < 32) {
    GPIO.out_w1tc = (1U << pin);
    GPIO.enable_w1ts = (1U << pin);
  } else {
    GPIO.out1_w1tc.val = (1U << (pin - 32));
    GPIO.enable1_w1ts.val = (1U << (pin - 32));
  }
}

/** Gibt {@code pin} wieder als Eingang frei - der externe Pull-up zieht den Bus auf HIGH. */
static inline void owRelease(int pin) {
  if (pin < 32) {
    GPIO.enable_w1tc = (1U << pin);
  } else {
    GPIO.enable1_w1tc.val = (1U << (pin - 32));
  }
}

/** Liest den aktuellen Pegel von {@code pin} (0 oder 1). */
static inline int owRead(int pin) {
  if (pin < 32) {
    return (GPIO.in >> pin) & 0x1;
  } else {
    return (GPIO.in1.data >> (pin - 32)) & 0x1;
  }
}


// =====================================================================================
// 6a. SENSORTREIBER: I2C
// =====================================================================================

/** Liest 1-4 Byte ab Register {@code reg} und setzt sie je nach {@code bigEndian} zu einem
 *  Rohwert zusammen. Vorzeicheninterpretation macht die Java-Sensor-Klasse. */
bool readI2CRegisterN(TwoWire &bus, uint8_t addr, uint8_t reg, uint8_t len, bool bigEndian, uint32_t &outValue) {
  if (len == 0 || len > 4) return false;

  bus.beginTransmission(addr);
  bus.write(reg);
  if (bus.endTransmission(false) != 0) return false;

  if (bus.requestFrom((int)addr, (int)len) != len) return false;

  uint8_t bytes[4];
  for (int i = 0; i < len; i++) {
    bytes[i] = bus.read();
  }

  uint32_t value = 0;
  if (bigEndian) {
    for (int i = 0; i < len; i++) value = (value << 8) | bytes[i];
  } else {
    for (int i = len - 1; i >= 0; i--) value = (value << 8) | bytes[i];
  }
  outValue = value;
  return true;
}

/** Schreibt die vom Host konfigurierte Init-Sequenz auf den Bus. */
void configureSensorOnBus(TwoWire &bus, char channelName) {
  const I2CSensorConfig &cfg = i2cConfigForChannel(channelName);
  bool ok = true;

  for (int i = 0; i < cfg.initWriteCount; i++) {
    const I2CWriteSpec &w = cfg.initWrites[i];
    bus.beginTransmission(cfg.address);
    bus.write(w.reg);
    for (int b = 0; b < w.dataLen; b++) {
      bus.write(w.data[b]);
    }
    ok &= (bus.endTransmission() == 0);
  }

  if (!ok) {
    reportSensorError(channelName, "I2C");
  }
}

/** Initialisiert den I2C-Bus eines Kanals neu und schreibt die Init-Sequenz erneut (nach
 *  Fehlern, um einen "hängen gebliebenen" Bus bzw. einen zwischenzeitlich stromlosen Sensor
 *  wieder in einen definierten Zustand zu bringen). */
void resetI2CBus(char channelName) {
  TwoWire &bus = busForChannel(channelName);
  bus.end();
  delay(5);
  const int *pins = (channelName == 'A') ? PINS_CHANNEL_A : PINS_CHANNEL_B;
  bus.begin(pins[0], pins[1], 400000);
  configureSensorOnBus(bus, channelName);
}

/** Wertet das Ergebnis eines kompletten I2C-Abtastzyklus aus. Nach jedem I2C-Zugriff
 *  (erfolgreich oder nicht) aufzurufen. Der Bus wird über resetI2CBus neu initialisiert
 *  - nach I2C_FAIL_STREAK_RESET_THRESHOLD Fehlern in Folge, sowie
 *  - beim ersten erfolgreichen Zyklus nach mindestens einem Fehler (Wiederanlauf: ein
 *    zwischenzeitlich abgesteckter Sensor hat seine Init-Register verloren). */
void noteI2CResult(char channelName, bool success) {
  int &streak = (channelName == 'A') ? i2cFailStreakA : i2cFailStreakB;
  if (success) {
    if (streak > 0) {
      streak = 0;
      resetI2CBus(channelName);
    }
    return;
  }
  streak++;
  if (streak >= I2C_FAIL_STREAK_RESET_THRESHOLD) {
    streak = 0;
    resetI2CBus(channelName);
  }
}
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
void loop() {
  handleSerialCommunication();

  if (!isStreaming) return;

  // HX711 liefert von sich aus 10 oder 80 Werte/Sekunde, unabhängig von der über RATE
  // eingestellten globalen Abtastrate - der Chip lässt sich nicht schneller machen, aber auch
  // nicht auf ein beliebiges Zeitraster zwingen. Deshalb hier bei jedem loop()-Durchlauf
  // (kostet im Leerlauf nur einen digitalRead) statt im festen sampleIntervalMs-Takt geprüft:
  // sonst hängt die Trefferquote von der zufälligen Phasenlage zwischen der Abfrage und dem
  // frei laufenden, nie exakt 10,000Hz genauen internen Oszillator des Chips ab - genau das
  // erzeugte die unregelmäßigen Lücken im aufgezeichneten Zeitstempel.
  if (configChannelA == TYPE_HX711) sampleHX711('A', PINS_CHANNEL_A[0], PINS_CHANNEL_A[1]);
  if (configChannelB == TYPE_HX711) sampleHX711('B', PINS_CHANNEL_B[0], PINS_CHANNEL_B[1]);

  // Alle übrigen Sensortypen im festen Takt der eingestellten Abtastrate.
  unsigned long currentTimeMs = millis();
  if (currentTimeMs - lastSampleTimeMs >= sampleIntervalMs) {
    lastSampleTimeMs = currentTimeMs;
    if (configChannelA != TYPE_HX711) sampleChannel('A', configChannelA, PINS_CHANNEL_A);
    if (configChannelB != TYPE_HX711) sampleChannel('B', configChannelB, PINS_CHANNEL_B);
  }

  // Das Frequenzspektrum braucht eine eigene, von der Abtastrate unabhängige Taktung.
  if (configChannelA == TYPE_I2S && i2sConfigChannelA.spectrumMode
      && currentTimeMs - lastSpectrumTimeMsA >= SPECTRUM_INTERVAL_MS) {
    lastSpectrumTimeMsA = currentTimeMs;
    captureAndSendSpectrum('A');
  }
  if (configChannelB == TYPE_I2S && i2sConfigChannelB.spectrumMode
      && currentTimeMs - lastSpectrumTimeMsB >= SPECTRUM_INTERVAL_MS) {
    lastSpectrumTimeMsB = currentTimeMs;
    captureAndSendSpectrum('B');
  }
}

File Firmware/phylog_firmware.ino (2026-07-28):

/*
 * PhyLog ESP32 Firmware v6.4
 * Flexible Kanal-Konfiguration für I2C-Sensoren (INA219, VEML7700) und Analog-Pins.
 * Welcher Sensortyp auf Kanal A/B aktiv ist, wird ausschließlich über das serielle
 * Kommando SET,<Kanal>,<Typ> von der Software gesetzt (siehe GUI.applySensorSelectionToFirmware).
 * Beide Kanäle starten daher mit TYPE_NONE, bis die Software eine Auswahl sendet.
 *
 * Kanal A und Kanal B hängen an PHYSISCH GETRENNTEN I2C-Bussen (Wire für A, Wire1 für B) - beide
 * haben eigene SDA/SCL-Pins, siehe PINS_CHANNEL_A/B. Das ist notwendig, sobald man auf beiden
 * Kanälen gleichzeitig einen I2C-Sensor (auch denselben Typ zweimal) betreiben will: ein einzelner
 * gemeinsamer Bus könnte einen an Kanal B angeschlossenen Sensor gar nicht erreichen.
 */

#include <Wire.h>

enum SensorType {
  TYPE_NONE = 0,
  TYPE_ANALOG = 1,
  TYPE_INA219 = 2,
  TYPE_VEML7700 = 3
};

SensorType configChannelA = TYPE_NONE;
SensorType configChannelB = TYPE_NONE;

const int PINS_CHANNEL_A[2] = {13, 12}; // GPIO13 (SDA), GPIO12 (SCL) - Bus "Wire"
const int PINS_CHANNEL_B[2] = {14, 27};  // GPIO15 (SDA), GPIO2 (SCL)  - Bus "Wire1"

const uint8_t ADDR_INA219   = 0x40;
const uint8_t ADDR_VEML7700 = 0x10;

bool isStreaming = false;
unsigned long sampleIntervalMs = 50; // Standard: 20 Hz
unsigned long lastSampleTimeMs = 0;

/** Letzter Zeitpunkt einer gemeldeten I2C-Fehlermeldung je Kanal, um das serielle Log bei
 *  dauerhaften Fehlern nicht mit Meldungen zu fluten (siehe {@link #reportI2CError}). */
unsigned long lastErrorReportMsA = 0;
unsigned long lastErrorReportMsB = 0;

/** Meldet einen fehlgeschlagenen I2C-Zugriff auf einen Kanal, höchstens einmal pro Sekunde je
 *  Kanal. Vorher wurde ein solcher Fehler komplett verschluckt (kein Datenpaket, aber auch keine
 *  Meldung) - dadurch war von der PC-Seite aus nicht zu unterscheiden, ob der Sensor gerade
 *  nichts Neues zu melden hat oder ob die I2C-Kommunikation grundsätzlich fehlschlägt. */
void reportI2CError(char channelName) {
  unsigned long &lastReport = (channelName == 'A') ? lastErrorReportMsA : lastErrorReportMsB;
  unsigned long now = millis();
  if (now - lastReport >= 1000) {
    lastReport = now;
    Serial.print("#ERR,I2C,");
    Serial.println(channelName);
  }
}

/** @return den I2C-Bus, der physisch zu diesem Kanal gehört (siehe Datei-Kommentar oben). */
TwoWire &busForChannel(char channelName) {
  return (channelName == 'A') ? Wire : Wire1;
}

/**
 * Liest ein 16-Bit-I2C-Register MSB-zuerst (big-endian, TI-Konvention - passend für den
 * INA219) über den angegebenen Bus. Gibt bei Erfolg true zurück und schreibt den Rohwert nach
 * outValue; bei einem Übertragungsfehler wird false zurückgegeben und outValue nicht verändert.
 *
 * <p>outValue ist bewusst uint16_t (nicht int16_t): der Rohwert wird unverändert als 0..65535
 * über die serielle Schnittstelle geschickt, die softwareseitige Sensor-Klasse entscheidet dann
 * je nach physikalischer Größe, ob und wie er vorzeichenbehaftet zu interpretieren ist (siehe
 * z. B. INA219CurrentSensor.decode in der Software).</p>
 */
bool readI2CRegister16(TwoWire &bus, uint8_t addr, uint8_t reg, uint16_t &outValue) {
  bus.beginTransmission(addr);
  bus.write(reg);
  if (bus.endTransmission(false) != 0) return false;

  if (bus.requestFrom((int)addr, 2) != 2) return false;

  uint8_t msb = bus.read();
  uint8_t lsb = bus.read();
  outValue = ((uint16_t)msb << 8) | lsb;
  return true;
}

/**
 * Wie {@link #readI2CRegister16}, aber LSB-zuerst (little-endian). Vishay-Bausteine wie der
 * VEML7700 senden ihre 16-Bit-Register in dieser Reihenfolge, anders als der INA219.
 */
bool readI2CRegister16LE(TwoWire &bus, uint8_t addr, uint8_t reg, uint16_t &outValue) {
  bus.beginTransmission(addr);
  bus.write(reg);
  if (bus.endTransmission(false) != 0) return false;

  if (bus.requestFrom((int)addr, 2) != 2) return false;

  uint8_t lsb = bus.read();
  uint8_t msb = bus.read();
  outValue = ((uint16_t)msb << 8) | lsb;
  return true;
}

/** Schreibt die Init-Konfiguration eines Sensortyps auf den angegebenen Bus (No-Op für
 *  TYPE_NONE/TYPE_ANALOG, die keine I2C-Konfiguration brauchen). Meldet einen Fehler, falls
 *  einer der Schreibvorgänge fehlschlägt - das würde den Sensor unbrauchbar machen, noch bevor
 *  überhaupt eine Messung versucht wird. */
void configureSensorOnBus(TwoWire &bus, SensorType type, char channelName) {
  bool ok = true;

  if (type == TYPE_INA219) {
    bus.beginTransmission(ADDR_INA219);
    bus.write(0x00); // Config Register
    bus.write(0x39); bus.write(0x9F); // 32V, Gain 8, 12-bit ADC
    ok &= (bus.endTransmission() == 0);

    bus.beginTransmission(ADDR_INA219);
    bus.write(0x05); // Calibration Register
    bus.write(0x10); bus.write(0x00);
    ok &= (bus.endTransmission() == 0);
  } else if (type == TYPE_VEML7700) {
    bus.beginTransmission(ADDR_VEML7700);
    bus.write(0x00); // ALS_CONF Register
    bus.write(0x00); bus.write(0x00); // ALS enable, Gain 1, IT 100ms
    ok &= (bus.endTransmission() == 0);
  }

  if (!ok) {
    reportI2CError(channelName);
  }
}

/** Konfiguriert beide Busse unabhängig - jeder Kanal bekommt nur den Init-Schreibvorgang für
 *  seinen EIGENEN Sensortyp, nicht den des anderen Kanals. */
void setupI2CSensors() {
  configureSensorOnBus(Wire, configChannelA, 'A');
  configureSensorOnBus(Wire1, configChannelB, 'B');
}

void processCommand(String command) {
  command.trim();

  if (command.equalsIgnoreCase("PING")) {
    Serial.println("#HELLO,PhyLog-ESP32,fw=6.4");
  } else if (command.equalsIgnoreCase("START")) {
    isStreaming = true;
    Serial.println("#OK,START");
  } else if (command.equalsIgnoreCase("STOP")) {
    isStreaming = false;
    Serial.println("#OK,STOP");
  } else if (command.startsWith("RATE,")) {
    long rateHz = command.substring(5).toInt();
    if (rateHz >= 1 && rateHz <= 200) {
      sampleIntervalMs = 1000 / rateHz;
      Serial.print("#OK,RATE,"); Serial.println(rateHz);
    }
  } else if (command.startsWith("SET,")) {
    // Format: SET,<Kanal>,<SensorTyp> (z.B. SET,A,INA219)
    int firstComma = command.indexOf(',');
    int secondComma = command.indexOf(',', firstComma + 1);

    if (firstComma != -1 && secondComma != -1) {
      char targetChannel = command.charAt(firstComma + 1);
      String sensorTypeName = command.substring(secondComma + 1);

      SensorType newType = TYPE_NONE;
      if (sensorTypeName.equalsIgnoreCase("INA219")) newType = TYPE_INA219;
      else if (sensorTypeName.equalsIgnoreCase("VEML7700")) newType = TYPE_VEML7700;
      else if (sensorTypeName.equalsIgnoreCase("ANALOG")) newType = TYPE_ANALOG;

      if (targetChannel == 'A') configChannelA = newType;
      else if (targetChannel == 'B') configChannelB = newType;

      setupI2CSensors();
      Serial.print("#OK,SET,"); Serial.print(targetChannel); Serial.print(","); Serial.println(sensorTypeName);
    }
  }
}
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

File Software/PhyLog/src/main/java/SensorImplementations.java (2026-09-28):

import java.util.List;

/**
 * Platzhalter-Sensor für unbelegte Kanäle.
 */
class NoSensor extends Sensor {
    public NoSensor() {
        super("-- Kein Sensor --", "", List.of());
    }

    @Override
    public double decode(int slot, long rawValue) {
        return 0.0;
    }

    @Override
    public List<Quantity> getQuantities() {
        return List.of();
    }

    @Override
    public String getFirmwareTypeName() {
        return "NONE";
    }
}

/**
 * INA219-Sensorprofil für Strommessungen. Die Firmware kennt seit v8.7 kein "INA219" mehr,
 * sondern nur noch generisches I2C (siehe {@link I2CSensor}) - Adresse, Init-Register
 * (Config + Kalibrierung) und die beiden Leseregister (Bus-Spannung, Strom) liefert allein diese
 * Klasse. Slot 0 (Spannung) wird zwar mitgelesen, aber (wie schon vor dem Umbau) von
 * {@link AcquisitionEngine} verworfen, da {@link #getQuantities()} nur Slot 1 (Strom) meldet.
 */
class INA219CurrentSensor extends I2CSensor {
    private static final double CURRENT_LSB = 0.0001; // 0.1 mA pro Bit
    private static final int ADDRESS = 0x40;

    public INA219CurrentSensor() {
        super("INA219 (Strom)", "A", List.of("A", "AMP", "MA"));
    }

    /**
     * Dekodiert den Rohwert für den Strom in Ampere.
     */
    @Override
    public double decode(int slot, long rawValue) {
        short signedRaw = (short) (rawValue & 0xFFFF);
        return signedRaw * CURRENT_LSB;
    }

    @Override
    public List<Quantity> getQuantities() {
        return List.of(new Quantity("Strom", "A", 1));
    }

    @Override
    public int getI2CAddress() {
        return ADDRESS;
    }

    @Override
    public List<Write> getInitWrites() {
        return List.of(
                new Write(0x00, 0x39, 0x9F), // Config-Register: 32V, Gain 8, 12-Bit-ADC
                new Write(0x05, 0x10, 0x00)  // Kalibrierregister
        );
    }

    @Override
    public List<Read> getReads() {
        return List.of(
                new Read(0x02, 2, true, 0), // Bus-Spannungsregister -> Slot 0 (ungenutzt, s. o.)
                new Read(0x04, 2, true, 1)  // Stromregister -> Slot 1
        );
    }
}

/**
 * VEML7700-Sensor zur Beleuchtungsstärkemessung in Lux. Wie {@link INA219CurrentSensor} seit
 * v8.7 ein generischer {@link I2CSensor} - die Firmware sieht nur noch "I2C-Gerät an 0x10 mit
 * dieser Init-/Lesekonfiguration", nicht mehr "VEML7700".
 */
class VEML7700Sensor extends I2CSensor {
    private static final int ADDRESS = 0x10;

    public VEML7700Sensor() {
        super("VEML7700 (Licht / Lux)", "lx", List.of("LX", "LUX"));
    }

    @Override
    public double decode(int slot, long rawValue) {
        // Skalierung auf Lux bei Gain 1x / Integrationszeit 25ms.
        return (rawValue & 0xFFFF) * 0.2304;
    }

    @Override
    public List<Quantity> getQuantities() {
        return List.of(new Quantity("Beleuchtungsstärke", "lx", 0));
    }

    @Override
    public int getMaxSampleRateHz() {
        return 40; // Integrationszeit 25ms -> max. 40 Hz neue Messwerte
    }

    @Override
    public int getI2CAddress() {
        return ADDRESS;
    }
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

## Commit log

2026-07-27 BUG SENSOR B
    [ESP_Bottom_V1.5.stl, ESP_Bottom_V1.6.stl, ESP_Top_V1.1.stl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]
2026-07-28 BUG? Sensor B, Easy Connection
    [PhyLog_firmware.ino]
2026-07-28 BUG? Sensor B, Easy Connection, Light Sensor
2026-07-28 Tara works, New Cabling for weight Sensor, Weight Sensor works?, Export fixed, etc
    [PhyLog_firmware.ino]
2026-07-30 I2S all on 3 Pins, nothing works
    [Sound_Sensor_Bottom_V1.1.stl]
2026-08-01 Fix fix fix, ChiSquareInfoDialog animation
    [Current_Sensor_Bottom_V1.4.stl, Current_Sensor_Bottom_V1.5.stl, ESP_Bottom_V1.6.stl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]
2026-08-01 Fix Sensorzwang
2026-08-12 A lot of fixes, "Momentaufnahme", Optimization
    [Magnet_Sensor_Bottom_V1.1.stl, Temperature_Sensor_Bottom_V1.0.stl, Voltage_Sensor_Bottom_V1.0.stl]
2026-08-12 Hotplug Sensor Optimization, Downsampling Chatpanel
2026-08-13 BLUETOOTTH, bisschen Buggy, and only .5m Reichweite
    [PhyLog_firmware.ino]
2026-09-04 TYPE I2C I2S 1WIRE ANALOG
2026-09-07 Bugs HX711
    [Force_Sensor_Bottom_V1.2.stl]
2026-09-07 Update Hardware – Quickstart.md
2026-09-16 Bug Fixes
    [Force_Sensor_Bottom_V1.2.stl]
